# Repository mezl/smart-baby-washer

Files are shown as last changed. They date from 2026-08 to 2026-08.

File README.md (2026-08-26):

<h1 align="center">Smart Baby Washer</h1>

<p align="center">
  <b>App and Home Assistant control for a baby-bottle washer, from an ESP32-C3
  that plugs inline on the panel cable.</b>
</p>

<p align="center">
  
  
  
  
  
</p>

<p align="center">
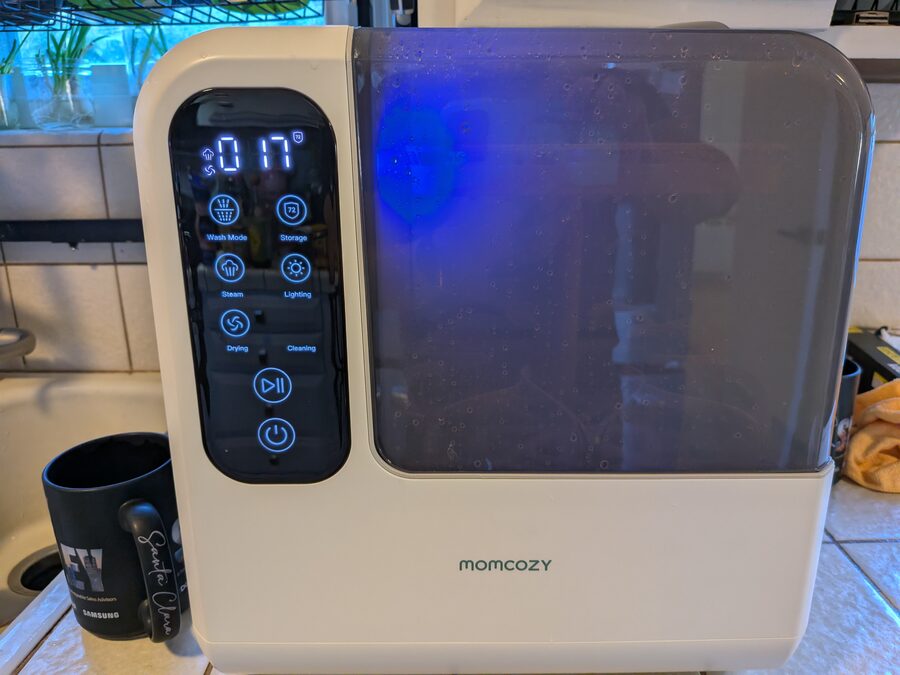
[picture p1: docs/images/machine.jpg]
A Momcozy D8 bottle washer on a kitchen counter, front panel lit, running a cycle.
  
</p>

- Sits on the 4-pin serial link between the front panel and the controller board,
  forwarding every frame and rewriting any byte in flight.
- **Reversible** — `CN2` is a plug-in connector, so the module goes inline on the
  existing cable. Nothing cut, nothing soldered to the OEM board.
- ⚠️ **Verified on two Momcozy D8 units** — an early button-panel one (board
  `BBW04001-UL-P`) and a later touch-panel one. Same firmware, unmodified, on
  both. See [what differs](#what-differs-between-the-two-units)

<p align="center">
  The ESP32-C3 sits on the CN2 UART between the main board and the front panel, and bridges to Home Assistant over WiFi.
</p>

## What it does

- **Web app + HTTP API** — pick a program, start/stop/resume, watch state,
  temperature and stage.
- **Home Assistant** — sensors, buttons, dashboard, notifications. Plain REST; no
  MQTT, no custom component.
- **Cycle runner** — six stock programs plus six of your own; durations and
  temperature targets persist; fills end on flow count, not a timer.
- **Interlocks the machine lacks** — no heater without a verified fill; pause on
  lid-open or no water; abort on over temperature, fill stall, fault bit or dead link.
- **Diagnostics** — drive each load on its own, inject `E0` `E3` `E4` `E5` `E7`
  (`E1`/`E6` have no bit), or run a whole cycle with nothing energised.
- **Live link decode** both directions, raw and rewritten, with temperature and
  flow graphs.
- Local only, no cloud. Logging is host-side; the ESP32 stores nothing.

<p align="center">
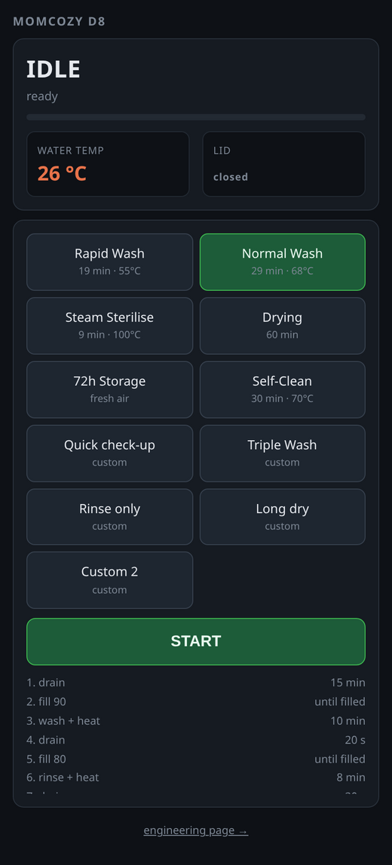
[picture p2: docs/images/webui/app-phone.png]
The app on a phone: state and water temperature, a grid of wash programs with one selected, a START button and the stage list.
  
</p>

<p align="center">
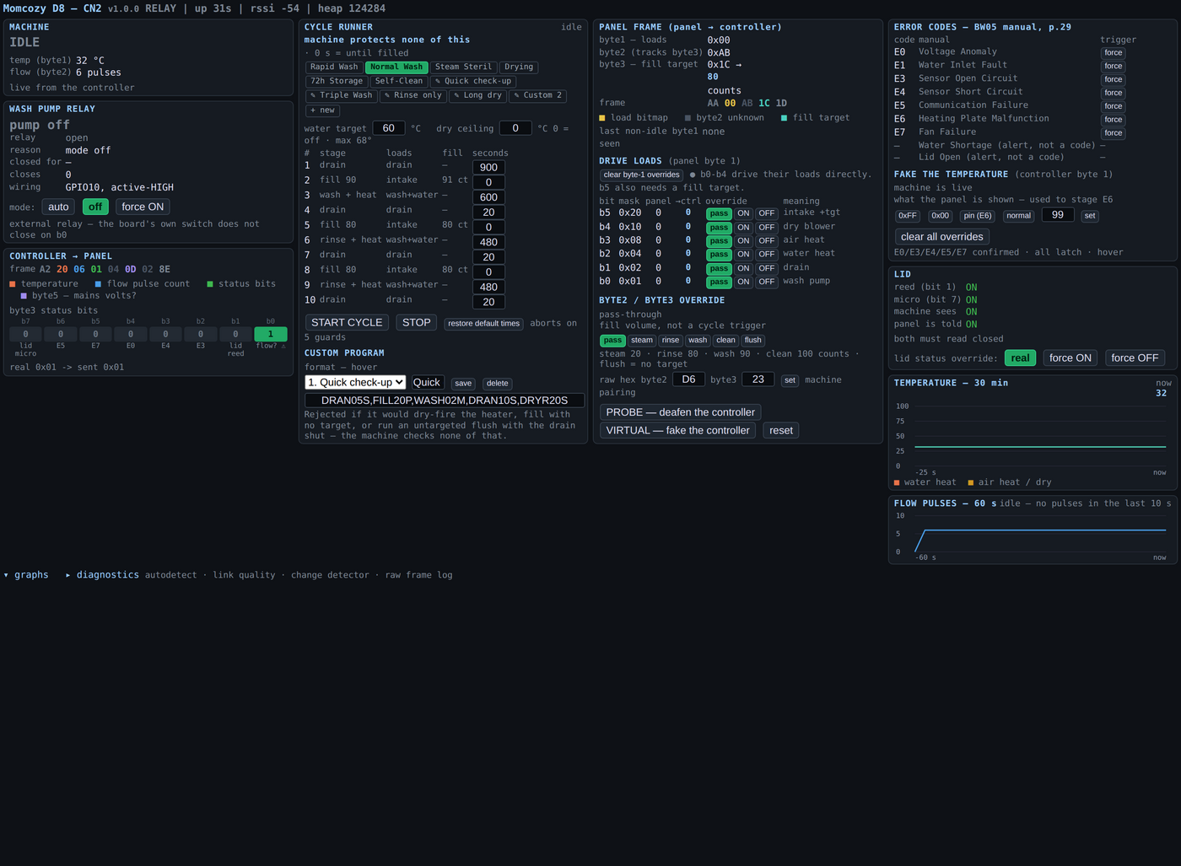
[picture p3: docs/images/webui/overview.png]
The engineering web page: machine state, wash pump relay, decoded frames, cycle runner, error codes, lid status, and temperature and flow graphs.
  
</p>

> ⚠️ It can drive 120 V heaters and a water pump directly, and the machine's own
> controller will not stop you. Read [`docs/safety.md`](docs/safety.md) first.

<p align="center">
  Timelines of a wash cycle and a self-clean cycle: temperature curve above six load lanes, every fill marked with its commanded target and the flow count delivered.
</p>

## What you build

- XIAO ESP32-C3 + a 4-channel BSS138 level shifter. Perfboard is enough; the
  carrier board in [`hardware/pcb/`](hardware/pcb/) is tidier, not better.
- Ground and +5 V pass straight through, so the panel never loses supply.
- ⚠️ Wire to the shifter's **printed pad names** — with HV facing the machine the
  pads read 4·3·2·1 down the board. The photo inset in the diagram shows it.
- 💡 Fit the external antenna. Inside a metal and wet plastic appliance the
  on-board one struggles, and losing WiFi means losing OTA.

<p align="center">
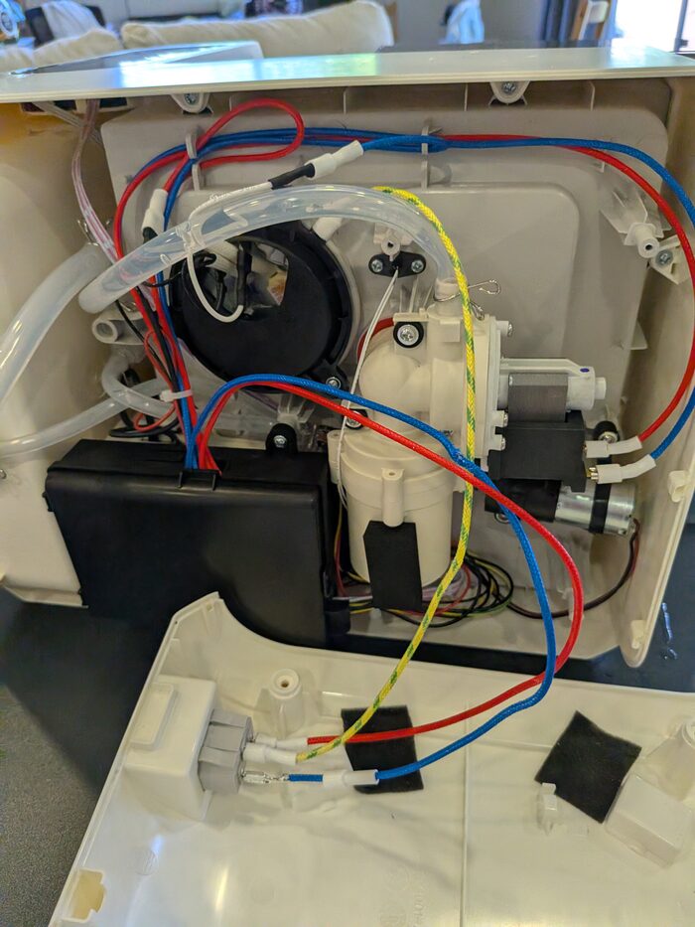
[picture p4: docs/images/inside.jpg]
The washer opened up: pump, tubing and wiring loom inside the base.
  
  &nbsp;
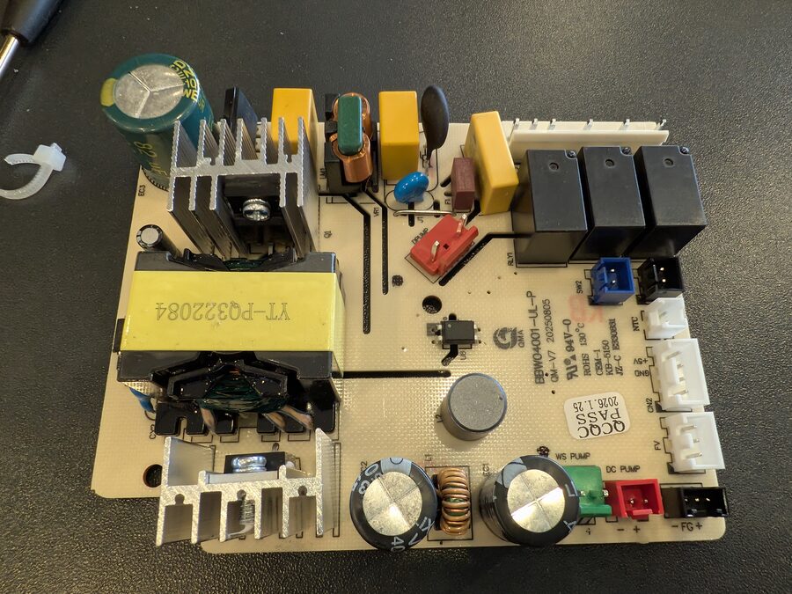
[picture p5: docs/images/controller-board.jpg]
The controller board out of the machine, showing the mains relays, the low-voltage connectors and the CN2 panel header.
  
</p>

<p align="center">
  As-built wiring: the controller and front panel connected through all four channels of a BSS138 level converter to a XIAO ESP32-C3, with power and ground passing straight through.
</p>

<p align="center">
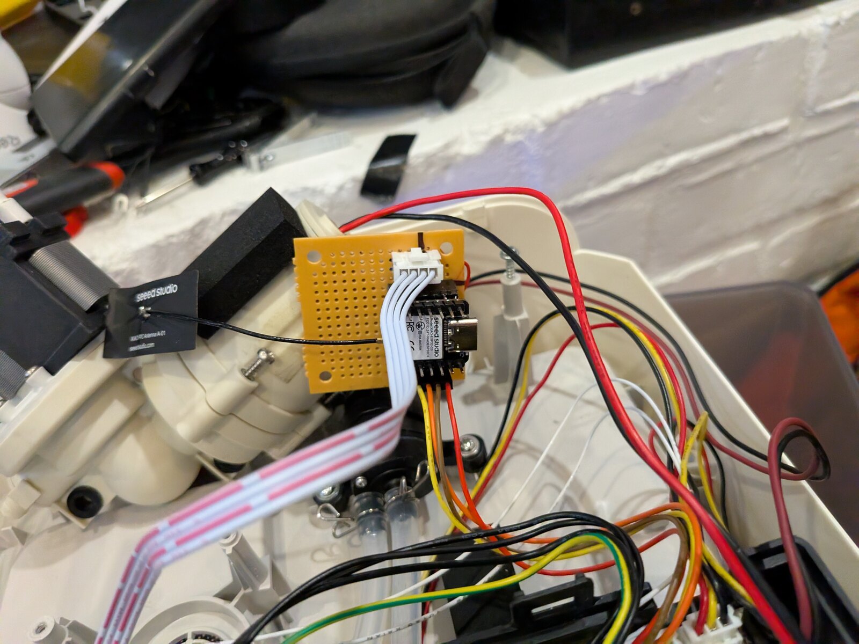
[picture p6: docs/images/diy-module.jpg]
The finished module inside the machine: a XIAO ESP32-C3 on a scrap of perfboard with a 4-pin JST lead to the panel link and an external antenna, tucked beside the pump and wiring loom.
  
</p>

## Quick start

```bash
cp firmware/include/secrets.h.example firmware/include/secrets.h   # WiFi + OTA password
cd firmware
pio run -e c3 -t upload
```

- Open `http://baby-washer.local/`.
- **Start in LISTEN mode** — it cannot drive a line, so nothing can hurt the
  machine while you confirm the wiring.

## Docs

1. ⚠️ [**safety.md**](docs/safety.md) — what the machine does *not* protect you from
2. [**build.md**](docs/build.md) — parts, tapping the link, level shifting, wiring
3. [**flash.md**](docs/flash.md) — firmware, OTA, not bricking it out of reach
4. [**use.md**](docs/use.md) — the app, the engineering page, Home Assistant

Reference: [board.md](docs/board.md) · [protocol.md](docs/protocol.md) ·
[water-plumbing diagram](docs/diagrams/water-plumbing.svg) ·
[cycles.md](docs/cycles.md) · [api.md](docs/api.md) ·
[troubleshooting.md](docs/troubleshooting.md) · [hardware/pcb/](hardware/pcb/)

## Does it fit my machine?

Verified on **two** Momcozy D8 units — an early one (board `BBW04001-UL-P`,
button panel) and a later one (touch panel). Same 9600 8N1 link, same frame
layout, same load bitmap, and the same firmware ran both unmodified.

| | |
|---|---|
| Momcozy D8, either revision | works; the differences below are cosmetic to the protocol |
| Another Momcozy, different board | the link will likely decode, but treat every load bit as unknown until you watch it act |
| Any washer with a separate panel | the approach applies; everything past that is your own work |

- Minimum requirement: a separate front panel talking to a controller over a 4-pin
  connector carrying ground, +5 V and two signal lines.
- [`docs/protocol.md`](docs/protocol.md) has the frame format;
  `POST /api/detect` finds the pin map without ever driving a line.
- A capture from a non-D8 machine is useful — open an issue with `/api/frames`
  output and the board part number.

### What differs between the two units

Measured across 4165 frames from the early unit and 1699 from the later one.

| | early (button panel) | later (touch panel) |
|---|---|---|
| controller byte 6 | `0x02` | **`0x03`** — the only byte that differs by revision |
| controller byte 4 | `0x04` | `0x04` |
| status bit 6 | seen only when starved of panel frames | also asserted **spontaneously**, held for hours, with a byte-perfect link |
| lid bits (1 and 7) | reported normally (`0x02`, `0x80`, `0x82`) | **never seen set** in any capture |
| wash pump on `b0` | low-side switch **does not close** — needs the external relay | **works** — no relay needed |
| fill targets | `0x07 / 0x1C / 0x20 / 0x23 / 0xFF` | same five values |
| heater duty | alternates `wash+heat` ↔ `wash-pump-only` | same |

Two of those matter in practice:

⚠️ **`b0` works on the later unit.** The external wash-pump relay in
[build.md](docs/build.md) is a workaround for the early board's dead low-side
switch. Check yours before wiring a relay it does not need — command `b0` during
a wash and listen.

⚠️ **Status bit 6 is the controller's panel-frame-starvation latch.** On the
later unit it latches until mains removal; the panel renders it as `E5`. Any
gap in forwarding — a slow boot, a wedged relay, an interrupted OTA — can
trip it, which is why the firmware bridges the pads in the first milliseconds
of `setup()` and why you should never flash mid-cycle. The full investigation,
including the wrong turns, is in [`docs/postmortem.md`](docs/postmortem.md).

**Do not assume the error-code table transfers.** Ours comes from the early
unit's manual (`BW05`, p.29). A later panel may number its codes differently,
and reading `E5` as "communication failure" on a machine whose link is provably
clean will send you a long way in the wrong direction.

## Licence

MIT — see [`LICENSE`](LICENSE). No affiliation with Momcozy. Names and part
numbers appear for identification only.

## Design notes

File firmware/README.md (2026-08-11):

# D8 CN2 panel-link sniffer / relay

ESP32-C3 firmware: a transparent man-in-the-middle on the CN2 link that forwards
every byte and can rewrite any of them in flight.

```bash
cp include/secrets.h.example include/secrets.h    # then edit it
pio run -e c3 -t upload                           # USB
OTA_PASSWORD=... pio run -e c3_ota -t upload      # WiFi, by mDNS
pio test -e native                                # 45 host-side cases
./tools/coverage.sh                               # + line/branch coverage
```

PlatformIO, Arduino framework, no external library dependencies. The pure frame
logic — framing, checksums, byte rewriting, the streaming checksum, thinning and
the autodetect decisions — lives in [`lib/cn2core/cn2core.h`](lib/cn2core/cn2core.h)
with no Arduino dependency, so it runs on a host at 100 % line and branch
coverage. `src/cn2.cpp` calls into that same header, which is what stops the tests
drifting into a parallel copy of the logic.

Then open `http://baby-washer.local/` — the user app — or `/dev` for the
engineering page.

⚠️ **Start in LISTEN mode.** It cannot drive a CN2 line at all. See
[`docs/wiring.md`](../docs/build.md#3-tap-it--listen-first).

## Everything else

| | |
|---|---|
| wiring, pin choice, level shifting | [`docs/wiring.md`](../docs/build.md) |
| the protocol | [`docs/protocol.md`](../docs/protocol.md) |
| HTTP API | [`docs/api.md`](../docs/api.md) |
| web UI | [`docs/webui.md`](../docs/use.md) |
| OTA design and its guards | [`docs/ota.md`](../docs/flash.md) |
| diagnosis | [`docs/troubleshooting.md`](../docs/troubleshooting.md) |
| ⚠️ what the machine does not protect you from | [`docs/safety.md`](../docs/safety.md) |

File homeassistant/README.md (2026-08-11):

# Home Assistant

Two files. No MQTT broker, no custom component, no cloud — HA polls the ESP32's
HTTP API directly.

```
packages/momcozy_d8.yaml    entities, commands, automations
lovelace-dashboard.yaml     the dashboard
```

## Install

1. Copy `packages/momcozy_d8.yaml` into `config/packages/`
2. In `configuration.yaml`:

   ```yaml
   homeassistant:
     packages: !include_dir_named packages
   ```

3. Set the ESP32's address — it appears **four times** in the package, in the
   `rest:` block and the three `rest_command:` entries
4. Restart HA
5. Settings → Dashboards → new dashboard → ⋮ → **Raw configuration editor** →
   paste `lovelace-dashboard.yaml`

## What you get

| Entity | |
|---|---|
| `sensor.d8_state` | Idle / Running / **Paused** / Complete / Stopped |
| `sensor.d8_water_temperature` | °C, uncalibrated and reads low |
| `sensor.d8_flow_count` | fill counter — cumulative for the **current fill**, zeroed by the controller when it completes |
| `sensor.d8_program` | the program the machine is set to |
| `sensor.d8_stage` | `3/10 — wash + heat` |
| `sensor.d8_error` | `E0`/`E3`/`E4`/`E5`/`E7`, or `none` |
| `binary_sensor.d8_running` | |
| `binary_sensor.d8_paused` | lid open, or the tank needs refilling |
| `binary_sensor.d8_lid` | on = **open** |
| `binary_sensor.d8_fault` | |
| `input_select.d8_program` | two-way — follows the machine if changed elsewhere |
| `script.d8_start_cycle` / `d8_stop_cycle` / `d8_resume_cycle` | |

Plus notifications when a cycle finishes or stops, and when a fault appears.

## ⚠️ What this actually controls

A cycle started from HA does **not** press the machine's buttons. Nothing the
panel does before it commands a load reaches the CN2 link, so there is no button
to press remotely. It runs the **ESP32's own cycle runner**, which drives every
load directly.

That matters because the machine protects almost none of it. Measured, not
assumed: the controller gates nothing except the intake motor, the heaters fire
with no water and the lid open, and **neither end has a fill timeout**. The
runner's interlocks are the only ones in the loop — see
[`../docs/safety.md`](../docs/safety.md) and
[`../docs/cycle.md`](../docs/cycles.md).

So:

- **Starting a cycle is a `script`, not a `switch`**, and every command is a
  `button`-style action. A stuck automation cannot leave a heater latched on.
- `script.d8_start_cycle` **refuses if the lid is open.** The machine itself will
  not.
- There is deliberately no "start at 3 am" example. Do not run this unattended.

## Notes

**Fault codes latch.** Clearing the condition is not enough — the machine needs a
power cycle before it will run again. The dashboard says so when a fault is
showing.

**Polling is 5 s.** The ESP32's own page polls at 1 Hz; 5 s is plenty for a
machine whose stages last minutes, and it keeps HA's recorder small. Lower
`scan_interval` if you want a tighter flow-count trace, but the device-side ring
at `/api/flowlog` is the right tool for per-pulse detail.

**Program indices** in `input_select` must match the firmware's order. If you
reorder the programs in `cn2.cpp`, reorder the list here too.

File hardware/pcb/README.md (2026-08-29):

# CN2 interceptor carrier board

A 18.6 × 27 mm, 2-layer carrier that sits in the CN2 cable between the D8
controller and its front panel. CN2 pins 3 and 4 (GND, +5 V) pass straight
through; pins 1 and 2 are routed through a level shifter to a XIAO ESP32-C3,
which then sees and can rewrite every byte in both directions.

<p align="center">
  Board: red = top copper, blue = bottom copper. J2 (panel) on the bottom edge, J1 (controller) on the top edge, level shifter nested between the XIAO's pin rows.
</p>

**J2 (panel) on the bottom edge, J1 (controller) on the top**, with the XIAO
between them and U2 nested *inside* the XIAO's 15.24 mm row gap — its own rows
are 10.16 mm apart, so it drops straight into the middle.

Standing the connectors on opposite edges rather than beside the XIAO is what
makes the board narrow: nothing sits left or right of the module except one
routing lane, so the width is the XIAO's row pitch plus that lane and two
edges. It also suits the cable run, since the two CN2 stubs leave the board in
opposite directions, the way they arrive.

### Which connector goes where is not arbitrary

Routing forces `LV1..LV4` onto `D1..D4` in order — they share a 0.94 mm channel
and any other order makes their spans overlap four deep. `D1..D4` are GPIO 3, 4,
5 and 6, and the firmware's as-built map is `rxb=5 txb=6 txp=3 rxp=4`: the
**controller** pair on GPIO5/6 and the **panel** pair on GPIO3/4. GPIO5/6 are
channels 3 and 4, which are the shifter's upper pins — so the controller has to
enter from the top edge.

Swap the connectors and the board still works, but only after swapping the four
`PIN_*` defines. `gen_pcb.py` reads `firmware/include/config.h` on every run and
fails if the two disagree, because a pin map that disagrees with the copper does
not announce itself: frames simply stop decoding.

## ⚠️ Mount U2 on the underside

Packing the shifter inside the XIAO's rows puts the two modules on top of each
other in plan view:

```
XIAO module   17.5 × 21.0 mm   x  0.22 .. 17.72    y  3.00 .. 24.00
shifter       15.7 × 13.2 mm   x  1.12 .. 16.82    y  6.90 .. 20.10
```

The shifter's outline sits entirely inside the XIAO's. On 2.54 mm sockets the
XIAO stands about 8.5 mm off the board and the shifter plus its own headers is
about 12 mm, so **they collide if both are fitted on top.**

**Solder U2 to the reverse side.** The pads are plated through-holes, so it makes
no difference electrically, and the two modules then sit back to back with the
PCB between them. Nothing in the Gerbers changes — it is purely an assembly
choice, but getting it wrong wastes a board.

If you would rather have both parts on top, put the shifter beside the XIAO
instead of between its rows; that costs roughly 14 mm of board length.

## Reading the silkscreen

| Mark | Meaning |
|---|---|
| `PNL` / `CTL` | which cable goes on which edge — panel bottom, controller top |
| `USB` + arrow | the end the XIAO's USB-C port faces |
| `[` `]` bracket | the side the JST latch faces on J1 and J2 |
| square pad | pin 1, on every connector and both modules |

**The USB arrow matters.** `D0` and `5V` are the two pins at the USB end of the
XIAO, and both sit at the low-y end here, so the port faces the **panel**
connector. Fit the module the other way round and every signal lands on the
wrong pin — there is no keying to stop you, and the board looks right.

**The bracket is the JST latch side.** An XH shroud is not symmetric: the ramp
the cable's clip engages is on one long side. Both are marked facing the nearest
board edge, so the clips are reachable from outside once the board is mounted.
Fit one backwards and the clip faces the board and cannot be released.

### ⚠️ USB access is tight — socket the XIAO, and plug USB in first

The USB port faces J2, about 1.4 mm from the connector. On 2.54 mm sockets the
module stands ~8.5 mm off the board, so the port clears the JST *housing* — but
a **mated** panel cable stands about as tall as the USB plug and sits directly
in front of it.

In practice: **plug the USB cable in before the panel cable**, or leave the
panel cable's service loop long enough to swing aside. This is not theoretical
— a whole debugging session on this project ran over USB serial with the radio
disabled, so losing USB access once assembled is a real cost.

If you would rather not live with it, both connectors can go on the **top**
edge, leaving the USB end of the board clear. Two 4-pin connectors need about
19.5 mm side by side, so the board becomes roughly 21 × 24 mm — near enough the
same area, with the USB fully accessible.

## Bill of materials — four parts

| Ref | Part | Notes |
|---|---|---|
| J1 | JST-XH 4-pin, 2.54 mm, vertical | **top** edge — cable to the **controller** CN2 |
| J2 | JST-XH 4-pin, 2.54 mm, vertical | **bottom** edge — cable to the **panel** CN2 |
| U1 | Seeed XIAO ESP32-C3 | 2×7, 2.54 mm pitch, 15.24 mm between rows |
| U2 | 4-channel BSS138 level shifter | 2×6, 2.54 mm pitch |

Plus two 1×7 and two 1×6 header strips if you want the modules socketed rather
than soldered down. Socketing the XIAO is worth it — it keeps `D5`, `D10` and
`D7` reachable for the flow and switch simulation, which is why the board carries
no separate header for them.

## The flow-meter relay is not on this revision

The previous board carried J3/J4, a relay for the flow-meter (FV) cable, so the
ESP32 could pass the real pulses through, rewrite their rate, or synthesise flow
on a dry bench. **It has been removed**, and that removal is most of the size
reduction: six more pins would not share an edge with the CN2 connectors, so
they forced the connectors back onto the left and right sides and the width from
18.6 mm to 31.5 mm — the flow relay cost more board than everything else on it.

If you put it back, the two findings that cost the most to learn are still worth
having:

- **The ESP32-C3 is not 5 V tolerant and there is no channel left to shift the
  flow signal** — all four converter channels are spoken for by CN2.
  `docs/hardware.md` records the meter as having a 10 kΩ internal pull-up and
  warns that running it at 5 V puts 5 V on a non-5V-tolerant GPIO. Measure FV
  Vcc first; if it is 5 V, `GPIO10` needs a divider, or feed the meter from the
  board's 3V3 so the whole signal drops to 3.3 V.
- **Cutting the line removes the meter's pull-up from the controller's input**,
  because that pull-up lives inside the meter and ends up on the far side of the
  break. The simulated output then has to drive the line actively, or the
  controller-side pin needs its own pull-up.

Only `GPIO7` (D5), `GPIO10` (D10) and `GPIO20` (D7) are free and safe on this
part — `GPIO2`, `GPIO8` and `GPIO9` are strapping pins and `GPIO21` emits ROM
boot chatter at every reset. All three stay reachable on the XIAO's own header
if you socket the module, which is the main reason to socket it.

## Connections

| ch | CN2 | | Converter | XIAO | UART |
|---|---|---|---|---|---|
| 1 | J2 PANEL pin 1 — RX, **input** | ← | `HV1` · `LV1` | `D1 / GPIO3` | `Serial1` **TX** |
| 2 | J2 PANEL pin 2 — TX, output | → | `HV2` · `LV2` | `D2 / GPIO4` | `Serial1` **RX** |
| 3 | J1 CONTROLLER pin 1 — TX, output | → | `HV3` · `LV3` | `D3 / GPIO5` | `Serial0` **RX** |
| 4 | J1 CONTROLLER pin 2 — RX, **input** | ← | `HV4` · `LV4` | `D4 / GPIO6` | `Serial0` **TX** |

That is `PIN_RX_BOARD 5`, `PIN_TX_BOARD 6`, `PIN_TX_PANEL 3`, `PIN_RX_PANEL 4` —
the as-built map already in `firmware/include/config.h`, so **a board built from
this needs no firmware change.** `gen_pcb.py` asserts it on every run.

Note this differs from the channel order in
[`docs/wiring.md`](../../docs/wiring.md#as-built--the-authoritative-table), which
describes the hand-wired module: there the controller landed on channels 1 and 2.
The electrical result is identical; only which pair uses which converter channel
moved, so that the connectors could sit on opposite edges.

**The rule that decides every connection is unchanged:** an *output* stub must
land on an ESP32 **RX** pin, an *input* stub must be **driven** by an ESP32 **TX**
pin. Wiring a TX pin to another output is the one way to damage a board.

Power: controller pin 4 = panel pin 4 = converter `HV` = XIAO `5V`, one net.
XIAO `3V3` → converter `LV`. All grounds common.

## ⚠️ Measure the level shifter before ordering

**Row spacing on 4-channel BSS138 modules is not standardised.** SparkFun's
BOB-12009 and most clones use 0.4″ (10.16 mm), but 0.5″ (12.7 mm) modules exist
and look identical in photos. Put calipers across yours, centre of one row to
centre of the other, then set `LS_ROW` at the top of `gen_pcb.py` and regenerate.

This is the single most likely way to get an unusable board back from the fab.

## How small it can go

18.6 × 27 mm is 502 mm², **39 % smaller than the 819 mm² it replaced** and
**41 % narrower** — which is the dimension that decides whether it fits a slot.

The width is now fully accounted for, and there is nothing left in it:

```
  0.5  edge
 16.8  XIAO pad block  (15.24 row pitch + 1.6 pad)
  0.4  clearance
  0.4  the one outer lane, shared by +5V (top) and GND (bottom)
  0.5  edge
 ─────
 18.6
```

The four CN2 signals never need a side lane at all: each connector pin sits
directly under the middle corridor, so it climbs straight out of its own pad
into its shifter pin, turning once. Only +5V and GND have to reach both the
XIAO's right-hand column and both connectors, and they share the single outer
lane one per layer. Remove that lane and the board is 17.8 mm, but those two
nets have nowhere to go.

**The height is set by the XIAO's body, not by its copper.** The pads span
15.24 mm; the module is 21.0 mm long, so it overhangs 2.88 mm at each end,
straight over the connectors. At 24 mm the modules physically sit on both JST
housings — the Gerbers look perfect and the boards arrive unbuildable.
`gen_pcb.py` now checks the module outlines against every connector pad on each
run for exactly this reason.

Going further would need **right-angle connectors** (the overhang stops
mattering and the board returns to ~24 mm), **discrete BSS138s instead of the
module**, which removes 12 through-holes and the nesting problem entirely, or
**4 layers**. Note that none of this saves money: JLCPCB charges the same for
anything up to 100 × 100 mm, so size only buys fit.

## Panelised for a JLCPCB minimum order

JLCPCB's minimum order is **5 pieces**, and its base tier covers any single
design up to **100 × 100 mm** — so a panel of copies costs what one small board
costs. `gen_panel.py` tiles the board into the largest grid that still fits:

```
  5 × 3 = 15 boards      panel 93.0 × 81.0 mm      5 panels = 75 boards
```

```bash
python3 gen_panel.py        # 5 x 3, the largest that fits
python3 gen_panel.py 3 2    # or any smaller grid
```

Output lands in `gerbers-panel/`, with `preview-panel.svg` to eyeball first.
The generator re-runs the board's DRC, connectivity, mechanical and pin-map
checks and refuses to panelise if any fail — a panel of a broken board is 15
broken boards.

### V-scoring, not mouse bites

The boards **abut with no gap**, which is what lets 15 fit. V-scoring needs a
straight line running the full width or height of the panel, and a grid of
identical rectangles is exactly that. Tab-routing would need a ~2 mm slot
between every pair and would cost a column.

Nothing had to change to make the copper safe for it: the board already keeps
every pad and track **0.5 mm** from its edge, and V-scoring wants 0.4 mm.

**The score lines are on their own layer** (`-V_Cut.gbr`), deliberately not on
`Edge_Cuts`. Anything on the outline layer is read as a route, and a router
following those lines would cut the panel into 15 loose boards at the fab
instead of scoring it. `Edge_Cuts` carries the panel border and nothing else.

### Ordering

Upload `gerbers-panel/` as a zip, then on the order page:

| Field | Value |
|---|---|
| Different Design | **1** |
| Delivery Format | **Panel by Customer** |
| Column × Row | **5 × 3** |
| Board size | 93 × 81 mm (JLC fills this from the Gerbers) |

Add a note asking for **V-scoring on the lines in `cn2-interceptor-panel-V_Cut.gbr`**.
Check their rendered preview before paying — it shows the score lines, and that
is the one place a misread would be visible before it is fabricated.

Panelised orders sometimes carry a small surcharge and the rules do change, so
confirm the price at upload rather than trusting this table. If it has moved,
`python3 gen_panel.py 2 2` gives four boards on a 37 × 54 mm panel, and a plain
single board is always `gerbers-kicad/`.

## Files

| | |
|---|---|
| `gen_pcb.py` | the board as explicit geometry — placement, nets, routing, its own DRC, preview |
| `gen_panel.py` | tiles the board into a JLCPCB-sized panel with V-score lines |
| `gen_kicad.py` | builds a native `.kicad_pcb` via the pcbnew API **and runs KiCad's own DRC** |
| `gen_eagle.py` | emits `.sch` and `.brd` from the same model |
| `gen_kicad_sch.py` | emits a native `.kicad_sch` from the same model |
| `cn2-interceptor.kicad_pcb` | native KiCad 7 board — open it, DRC it, edit it |
| `cn2-interceptor.kicad_sch` | native KiCad 7 schematic — nets joined by labels |
| `cn2-interceptor.sch` / `.brd` | Eagle 9 XML, for Eagle / Fusion 360 |
| `gerbers-kicad/` | **exported by KiCad itself** — this is the set to send to a fab |
| `gerbers/` | my own writer's output, kept as a cross-check |
| `gerbers-panel/` | **the 5 × 3 panel** — upload this zip for a 15-up order |
| `drc-report.txt` | KiCad's DRC output from the last run |

Regenerate everything:

```bash
python3 gen_pcb.py      # geometry DRC + connectivity + my gerbers + preview.svg
python3 gen_kicad.py    # .kicad_pcb + KiCad's own DRC report
python3 gen_kicad_sch.py  # .kicad_sch
python3 gen_eagle.py    # .sch + .brd   (refuses to run if the DRC fails)

kicad-cli pcb export gerbers --output gerbers-kicad \
  --layers F.Cu,B.Cu,F.Mask,B.Mask,F.SilkS,Edge.Cuts \
  --no-x2 --subtract-soldermask cn2-interceptor.kicad_pcb
```

There is one source of truth. The schematic, the board and the Gerbers are three
renderings of the same Python model, so they cannot drift apart.

## What has been checked, and what has not

**Checked by KiCad itself** (`gen_kicad.py`, via `pcbnew.WriteDRCReport`):

```
violations       0   (excluding 4 lib_footprint_issues, see below)
unconnected pads 0
footprint errors 0
```

The four remaining reports are all `lib_footprint_issues: the current
configuration does not include the library 'cn2interceptor'` — the footprints are
generated into the board file rather than pulled from an installed library, so
KiCad cannot find a library to check them against. That is a bookkeeping
complaint, not a geometry or connectivity one.

**Checked by `gen_pcb.py`** on every run, independently of KiCad:

- 2186 pairwise clearance checks at 0.20 mm — copper-to-copper on each layer,
  and every track against every through-hole pad on both layers
- annular ring ≥ 0.30 mm, drill ≥ 0.30 mm, 0.5 mm edge keepout
- connectivity: every pad is on a net, every net has ≥ 2 pads, and every net
  forms a single connected island rather than two stranded halves
- both Eagle files parse as well-formed XML
- the board's pin map is compared against `firmware/include/config.h` and the
  run fails on a mismatch
- module bodies (not just their pads) are checked against every connector pad
- silkscreen is checked to stay on the board and off every pad

**Not checked.** Be clear-eyed about this list:

- **Nothing has been fabricated.** No board has been made or assembled.
- **The Eagle `.sch`/`.brd` have not been opened in Eagle or Fusion.** They parse
  as well-formed XML and are generated from the same verified model, but no Eagle
  install has confirmed they import cleanly. The KiCad board has been through
  KiCad's own DRC and Gerber export.
- **No ERC has been run.** KiCad 7's CLI has no `sch erc` command (that arrived
  in KiCad 8). The `.kicad_sch` parses and plots cleanly through `kicad-cli sch
  export`, which is not the same as passing ERC — open it in Eeschema and run
  ERC if you want that confirmed.
- **Footprint dimensions come from datasheets, not from measuring your parts.**
  The XIAO's 15.24 mm row spacing is well documented; the level shifter's is not
  — see the warning above.
- **No thermal or current analysis.** It carries logic signals and the panel's
  own 5 V supply, which the OEM cable already carried, so this is unlikely to
  matter. It has not been calculated.

**Before ordering:** open the Gerbers in a viewer (JLCPCB and PCBWay both show
you the rendered board at upload), check the level shifter footprint against your
actual module, and confirm the JST-XH pin order matches your cable.

## Safety

The board carries the panel's 5 V supply and its data lines. It does not touch
mains. But what you can then *do* with it does —
see [`docs/safety.md`](../../docs/safety.md): byte 1 of the panel frame is a
direct load bitmap, and three of its bits fire heaters with no cycle running and
no water in the machine.

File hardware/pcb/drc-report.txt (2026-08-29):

** Drc report for  **
** Created on 2026-08-29 16:27:00 **

** Found 4 DRC violations **
[lib_footprint_issues]: The current configuration does not include the library 'cn2interceptor'.
    Local override; Severity: warning
    @(3.8900 mm, 7.1500 mm): Footprint U2
[lib_footprint_issues]: The current configuration does not include the library 'cn2interceptor'.
    Local override; Severity: warning
    @(1.3500 mm, 5.8800 mm): Footprint U1
[lib_footprint_issues]: The current configuration does not include the library 'cn2interceptor'.
    Local override; Severity: warning
    @(5.1600 mm, 25.4000 mm): Footprint J1
[lib_footprint_issues]: The current configuration does not include the library 'cn2interceptor'.
    Local override; Severity: warning
    @(5.1600 mm, 1.6000 mm): Footprint J2

** Found 0 unconnected pads **

** Found 0 Footprint errors **

** End of Report **

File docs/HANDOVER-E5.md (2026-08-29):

# HANDOVER: Momcozy D8 "unit 2" E5-at-boot — for the next agent

Written 2026-08-27 by the outgoing agent after a three-day investigation that
fixed everything except this. Read `postmortem.md` and `boot-review.md` after
this file; they carry the full evidence chains. Trust the measurements in
this document; distrust every narrative, including mine.

## 0. The one-line problem

Since Aug 26 ~17:45, the washer's controller latches status **bit 6** (panel
shows **E5**) ~5 s after every power-on **when the ESP32 interceptor module
is inline**, and boots clean when the panel cable is connected directly
(bare). The machine worked perfectly with the same module, same firmware,
same NVS at 15:31 the same day. Nothing that is constant across that
boundary can be the cause; everything software-side has been proven constant
or was wiped.

## 1. System map

- **Machine**: Momcozy D8 bottle washer, later touch-panel revision.
  Controller board talks to front panel over `CN2` (4-pin: GND, +5V, two
  UART lines, 9600 8N1). Frame formats in `docs/protocol.md`.
- **Module**: XIAO ESP32-C3 + 4-ch BSS138 shifter, INLINE on CN2 (cable cut,
  both halves land on the module). Powered FROM CN2 pin 4 → it reboots with
  the machine. **As-wired pin map: rxb=5 txb=6 txp=3 rxp=4** (differs from
  docs/build.md which describes 3/4/5/6 — the owner rebuilt it Aug 25; NVS
  map matches physical, verified: frames decode on 5/4, dead on 3/6).
  IP `192.168.14.13`, mDNS `d8-sniffer.local`. Firmware in this repo,
  `firmware/`; deployed 1.17.7. OTA: `POST /update?key=<OTA_PASSWORD>` —
  password in `firmware/include/secrets.h` (gitignored, on the dev box).
- **Smart plug**: Shelly Plug US **Gen4** `192.168.14.95`, name "D8 Washer",
  `initial_state=on`. HTTP RPC, no auth. Real power metering. `toggle_after`
  gives a true self-restoring power cycle — `tools/shelly.py`
  (status/on/off/cycle) or `POST <esp>/api/kasa?cycle_s=N`.
- **HA**: `homeassistant.local:8123` (ssh alias `ha`, key auth, /config).
  Shelly integration live; `packages/momcozy_d8.yaml` REST-polls the ESP.
  Dashboard tab: `/dashboard-cradlewise/d8`. NO daemons — owner directive:
  ESP32 must be self-contained; HA is display-only.
- **Repos**: `~/software/d8-smart` (private, full history) and
  `~/software/smart-baby-washer` (public mirror). Firmware source of truth
  the owner edits from: `~/software/momcozy_d8/cn2sniffer`.

## 2. Owner directives (standing, do not violate)

- CPU relay is the operating mode; NEVER auto-switch to wire mode. Wire is a
  diagnostic, on explicit request. (Both persist via NVS `wire`.)
- No PC/HA daemons in the run/recovery path.
- Self-heal (`/api/heal`) is opt-in OFF; its strike counter resets only by
  human command. It once power-cycled the machine all night — see §6.
- Repos stay private until the owner flips them; never commit secrets.

## 3. Tooling you have

- ESP API: `/api/status` (everything), `/api/frames?n=` (timestamped ring,
  ~60 s deep), `/api/hist` (dedup frame history; array is oldest→newest,
  `first/last` = frames-ago — MISREAD TWICE, cost hours), `/api/graph`
  (temp/flow/power trends), `/api/panel_ovr`, `/api/mode_ovr`, `/api/wire`
  (GET shows live+stored), `/api/pinmap`, `/api/kasa` (`type=shelly`,
  `test`, `cycle_s`), `/api/nvswipe?confirm=yes`, `/api/heal`, `/api/prof`,
  `/api/wirecheck` (edge counts on all four pads — proves conduction).
- `firmware/minimal/main_min.cpp` (env `c3min`): bridge+WiFi+OTA only, the
  exoneration instrument. NOTE: no WiFi reconnect — if a boot misses
  association it stays dark; power cycle again.
- OTA over the flaky link: fresh-boot trick — Shelly `toggle_after=6`, wait
  for `/api/version`, sleep 10–12 s, then upload full speed. Usually lands
  within 4 rounds. Uploads die if attempted on an "aged" link.
- Host tests: `pio test -e native` (111 green, includes the E5Model suite
  that reproduces every firmware-caused E5 class and forbids regressions).

## 4. Precise symptom (from frame captures — `captures/boot-frames-e5-*.txt`)

- Controller boots **clear** (byte3=0x00), replies to the panel's 200 ms
  polls within 3–12 ms, checksums perfect, then latches byte3=0x40 at
  **t≈5.1 s** between two byte-identical polls.
- Controller frame **byte 5**: healthy era idles `0x09` (0b1001); broken era
  `0x0A/0x0B` (bit1 ON; bit0 flickers). It initializes ~0x00→0x0A at
  t≈0.7 s. It has read steady-`09` for stretches (once 5+ minutes) and the
  latch STILL occurred on the next boot — so byte5-bit1 correlates but the
  gate may sample earlier than any window we catch, or byte5 is not the gate.
- The latch survives cuts of 5 s–10 min. Historical cut data (CSV in
  `captures/`): during Aug-23-era locks, 60 s cuts 0/5, 120 s 3/5, 180 s 2/2
  — but the CURRENT condition relatches at every boot regardless.
- A latched controller ignores external load commands (proven: intake+target
  → zero flow; 60 s wash+heat → 0.0 °C rise) but its frames keep flowing.

## 5. The exoneration ladder — do not re-climb it

Each rung was TESTED, not argued (details in postmortem/boot-review):
1. Firmware logic — 20-line minimal image (silicon bridge from first app
   instruction, no logic in data path): **latches**.
2. Image size / boot speed — 23 % smaller, zero init: latches.
3. Every firmware version, incl. rebuilt same-day-working 1.16.3: latches.
4. NVS — full wipe to virgin + minimal re-provision: latches.
5. Pin map — re-verified empirically both ways (decode dead on 3/4/5/6,
   alive on 5/6/3/4).
6. GPIO10 boot drive (real bug, fixed 1.17.3 — wsr pin untouched when off):
   not the cause.
7. Frame content/timing — byte- and ms-identical to working logs.
8. Masks (`e5filter`), wire vs CPU, boot-bridge timing (t≈300 ms): no effect.
9. ROM-stage pad analysis (JTAG pulls on GPIO4/5/6): cannot pull a line low;
   constant since day one.
10. **Bare machine: clean** (owner-run, repeated).

## 6. Open contradictions — the real leads

- **The overnight 38 W**: Aug 26 23:00→Aug 27 08:50, HA's Shelly power
  history shows a flat ~38 W pump-class load for 7.6 h starting AT a boot,
  during virgin-NVS **wire mode** (ESP TX physically detached) with the
  panel E5-latched. Owner states the controller never self-starts loads on
  boot. Then WHO drove 38 W? Unresolved. Suggest: capture what a LATCHED
  panel actually transmits (nobody ever verified it stays idle in all latch
  entry paths), and what byte1 the controller sees at such a boot.
- **The Wednesday 15:31→17:45 differential**: that afternoon contained heavy
  cycle testing (heat, vibration, dozens of hard power cycles) and a flush
  bug that ran water ~2 min (see postmortem). No code change survives the
  elimination ladder. Something PHYSICAL changed. Candidates, in my order:
  BSS138 channel stressed/failing at analog margins; solder joint; CN2
  connector seating; controller input stage damaged; and (weakly) some
  panel/controller NVM state that bare-boot masks — though bare-clean argues
  against controller NVM.
- **byte5 semantics**: never decoded. Bits 0/1 swap between healthy/broken;
  a new value 0x06 appeared once after the pump-night. Manipulating lid,
  tank, buttons moved nothing. Worth mapping properly (drive each machine
  input while streaming `fb`).

## 7. Ranked next experiments

1. **USB split-power test** (decisive, cheap; owner has the module
   accessible): USB-C charger into the XIAO → ESP never reboots with the
   machine → bridge alive from the controller's first microsecond → Shelly-
   cycle the machine. Clean boot ⇒ ROM dark-window timing was the cause AND
   the permanent fix (leave USB in). Latch ⇒ analog presence confirmed.
   Note XIAO diode-ORs USB and 5 V rail; dual feed is safe.
2. **Multimeter on the shifter during a latch** (HV1..4 idle ≈5 V via 10 k
   pull-ups; a dead channel reads floating/low; wiggle-test joints).
3. **Latched-panel transmission capture**: `/api/frames` while the panel
   displays E5 through a fresh latch — verify it truly idles 0x00 in every
   entry path (bears on the 38 W mystery).
4. **Scope/logic-analyzer on CN2 at the controller connector** during a
   module boot vs a bare boot — the only view that sees what the
   controller's input pin actually receives during t=0–5 s.
5. If all else stalls: swap the BSS138 board (~$1) on spec; it is the
   component most exposed to that afternoon's stress and least observable.

## 8. Lessons paid for in hours — read before acting

- `HardwareSerial::setPins(samePins)` is a silent no-op; the GPIO-matrix
  bridge steals pads invisibly to periman. Reconnect TX signals explicitly
  (see wireSet(false)). This one cost 12 hours of ghost-hunting.
- Test UI through a BROWSER, not curl: the board serves ONE http client;
  parallel fetches race and the loser is dropped (chain posts).
- The shared `Preferences s_prefs` handle breaks after any begin()/end()
  pair elsewhere; use local handles for every persist (several fixed).
- A 0xFF flush is controller-LATCHED: stopping it = intake off, drain held
  ~20 s, then release. Plain release leaves water running.
- FramePos alias: idle-stream byte loss self-sustains and XOR-validates;
  detection needs the byte-1 invariant + wire-gap re-lock (in cn2core, host
  tested).
- `pkill -f <pattern>` matching your own command line kills your own shell.
- Owner's instincts have repeatedly out-diagnosed instrument readings.
  When they say "not X", retire X quickly and retest assumptions instead.

## 9. Artifact index

- `docs/postmortem.md` — full multi-day evidence narrative + retractions
- `docs/boot-review.md` — instruction-level boot audit
- `captures/boot-frames-e5-20260826.txt` — the latch, frame by frame
- `captures/unit2-firstcycle-*` — healthy-era reference traffic
- `captures/unlock-attempts.csv`, `ha-*-final.*` — cut/latch field data
- `firmware/test/test_cn2core/` — 111 host tests incl. the E5Model suite
- HA history: `sensor.d8_washer_d8_washer_power` — the overnight 38 W curve

Good luck. The machine's owner wants a washer, not a mystery — if experiment
1 fixes it, stop there and let the analog question rest.

---

## Update 2026-08-28: module went fully dark

The ESP died in place overnight (last alive 2026-08-27 after the 1.17.8
flash, link healthy). Evidence: never associates with WiFi (ARP
incomplete), absent from a full /24 sweep, machine standby draw normal
(1.8 W). Not recoverable remotely: 3 power cycles + 30 s cut + 5-min
cold cut all failed. Chip is not booting.

Significance: strongly supports the hardware-degradation branch. A
failing power path (CN2 pin-4 rail / regulator) explains BOTH the
E5-at-boot onset on 08-26 (rail sag disturbing the link during boot)
AND the final no-boot state -- one fault, progressing.

Decisive test unchanged (= ranked experiment #1, now also the recovery
step): USB-C into the XIAO.
- Boots on USB -> rail/feed dead -> E5 root cause likely found; run the
  module on USB power permanently.
- Dead on USB -> board failed -> replace XIAO, `pio run -t upload`,
  pin map 5/6/3/4 is the compiled default since 1.17.8.

Note: with the module inline and unpowered the panel<->controller link
is SEVERED (bridge exists only while the ESP runs). Machine unusable
until physical access; panel-direct-to-CN2 restores standalone use.

## Update 2026-08-28 (later): machine WORKS with the "dead" module inline -- diagnosis nearly closed

Kai reports the machine working again, module untouched, ESP still absent
from the network. This overturns the "chip not booting" call: the link
physically routes through the module, so a working machine PROVES the
bridge is forwarding, i.e. the CPU boots and runs instantBridge (first
instruction, register-state only, ~uA). Only the RADIO is dead.

Coherent single-fault story, now spanning every observation:
degrading 5V feed (CN2 pin-4 rail / regulator). Quiescent CPU + GPIO
bridge survive; WiFi startup bursts (~300 mA) collapse the rail.
- Pre-08-26: rail healthy -> everything worked.
- 08-26 onward: rail sags during WiFi startup -> link disturbed at
  t~5.1 s after boot (exactly the radio-burst window) -> controller
  latches E5 every boot.
- 08-28: degradation progressed; WiFi cannot start at all (possibly a
  brownout-reset loop; bridge re-establishes within ms each pass) ->
  module offline, machine runs CLEAN because the disturbance source
  (radio) never comes up.

The module has degraded itself into the "dumb wire, no radio" arm of the
experiment ladder -- and the machine running clean in that arm points at
WiFi power draw on the shared rail, not the data path and not firmware.

Confirmation + fix in one step (unchanged, USB split-power): feed the
XIAO from a USB-C charger. Expected: WiFi returns AND E5 stays away.
If E5 returns with WiFi on USB power, this story is falsified and the
shifter/analog branch reopens.

Interim state: machine usable from the panel; no web UI / HA / logging
until the module gets USB power.

## Update 2026-08-28 (USB split-power attempt): back-feed invalidates the test

Kai fed the XIAO from USB (PC) with the machine open. Result: ESP alive on
WiFi (1.17.8), link PERFECT (2381 frames, 0 bad checksums), but the panel
still shows E5 and the controller reports st=0xC2.

WHY THE TEST DID NOT RUN: the split was never achieved. wiring.md is
explicit -- "controller pin 4 (+5 V) = panel pin 4 = converter HV = XIAO
5V, one net". USB VBUS therefore back-feeds the machine logic rail through
the XIAO 5V pad. PROVEN: with the Shelly at 0.0 W (mains fully off) the
controller kept emitting B>P frames every 200 ms -- the controller and
panel MCUs were running on USB power.

Consequences:
- The Shelly can no longer reset the controller/panel while USB is
  plugged, so the E5 latch CANNOT be cleared and every "power cycle" is a
  brownout dip (loads drop, logic stays up) -- itself a good way to INDUCE
  a fault. st was observed going 0x82 -> 0xC2 across one such dip.
- All boot-latch results taken in this configuration are void.
- st=0xC2 = 0x40 latch + 0x82 lid-open (machine is physically open;
  0x82 is expected while the lid is off and is NOT a fault).

REQUIRED to actually run the experiment: disconnect ONLY the wire from the
CN2 pin-4 (+5 V) net to the XIAO **5V pad**. Keep everything else --
converter HV stays on the machine 5 V net, GND common, all four signal
lines. Then the XIAO is USB-only, the machine is Shelly-controlled, and no
back-feed exists.

That cut is simultaneously the decisive TEST and the candidate FIX: it
removes the module inrush/WiFi load from the machine 5 V rail at boot,
which is the surviving hypothesis for the t~5.1 s latch.

## Update 2026-08-28 (evening): WiFi ELIMINATED — radio-off test with serial telemetry

New tooling (fw 1.18.3): a **USB serial console** plus an NVS `nowifi`
mode that skips net/web/kasa entirely. This finally decoupled telemetry
from the radio, which had been the last unexonerated load. Console keys:
`s` status, `m` 1 Hz monitor, `c` CPU relay, `w` wire, `e`/`E` E5 mask
on/off, `r` reboot, `W`/`X` radio on/off, `?` help. Flash over USB with
`pio run -e c3 -t upload --upload-port /dev/ttyACM0` -- no OTA needed.

RESULT: with the radio completely dark, the controller STILL latches.
Captured at 1 Hz over serial, twice:

    t=40s  A2 16 00 82 04 00 03 31   clean boot, NO latch
    t=41s  A2 16 00 82 04 0C 03 3D   byte5 settles 0x00 -> 0x0C
    t=45s  A2 16 00 C2 04 0C 03 7D   bit 6 set -- exactly 5 s later
           bad_c frozen at 54 across the whole window: ZERO bad frames

**WiFi power draw and RF are therefore NOT the E5 trigger.** The theory
that survived three days is dead, and with it the whole rail-load branch
as far as the radio is concerned.

Confirmed structure of the fault: the controller boots CLEAN, communicates
perfectly for 5 s, then raises bit 6 with no corrupted frame anywhere in
between. It is a timed decision, not a reaction to bad data.

Byte 5 is the earliest divergence and now looks like a state code, not a
bitfield: 0x09 healthy idle, 0x0A on the 2026-08-26 latch (lid closed),
0x0C today (lid open, machine on the bench). Still undecoded, but it
settles ~1 s after boot -- 4 s BEFORE the status bit -- so whatever the
controller decides, it decides early.

Also established today:
- The 5 V wire removal DID isolate the controller: during a mains cut its
  line goes to noise (bad frames, ~500 byte/s of garbage) and ok_c freezes,
  i.e. the controller is genuinely unpowered. The PANEL stays up on USB.
- Therefore the panel no longer resets with the machine, so its own E5
  latch cannot be cleared by the Shelly. Clearing it needs mains off AND
  USB unplugged together.
- Bit 6 can only be masked in CPU relay mode. In wire mode the pad bridge
  means no byte passes through software and the E5 filter is inert however
  it is set -- worth knowing before trusting `e5f_mode=2`.

Open at the end of the session: the machine reads 0.0 W on the Shelly with
the outlet ON (standby was 1.4-1.8 W), i.e. it is not receiving mains --
a physical matter with the unit open on the bench.

Remaining ranked experiments: unchanged, minus WiFi. The fault is a
5-second timed decision by the controller that only occurs with the module
electrically inline, so the next evidence must come from a meter or a
scope on the CN2 lines, not from firmware.

## 2026-08-28 (night): ROOT CAUSE FOUND — the ESP->controller TX channel is open

Kai ran the clean A/B: CN2 back to the controller with the ESP entirely
removed -> NO E5, machine works. ESP back inline -> E5. The module is the
cause, as every earlier test implied. `/api/pinprobe` then localised it to
a single channel, reproducibly (4 probes, 2 rounds):

    GPIO6 -> CONTROLLER   pullup=1 pulldown=0 drive=1/0   external pull-up MISSING
    GPIO3 -> PANEL        pullup=1 pulldown=1 drive=1/0   external pull-up PRESENT

Both pads drive and read back their own level (edges 200/200), so the ESP
is fine. The difference is entirely external, and the panel channel is the
built-in control: same board, same probe, opposite result.

`pulldown` is the discriminating measurement. With the pad's INTERNAL
pull-down (~45k) enabled, a healthy channel still reads HIGH because the
shifter's 10k pull-up wins. The controller channel reads LOW -> no external
pull-up is present on that LV net -> that channel is open or unpowered.

Consequence, and it explains every observation of the last three days:
the ESP can pull the controller's RX line low through the MOSFET body diode
but cannot return it high, so the controller receives nothing usable. It
declares panel starvation ~5 s after boot and raises bit 6 -- which is
exactly the unit-1 semantics of that bit, and exactly the 5 s timing
captured over serial. Meanwhile:

- the ESP RECEIVES both directions perfectly (bad=0) -- RX paths are
  independent of this break, which is why every capture looked healthy;
- the bare machine works -- the panel drives the controller directly and
  the shifter is not in the path at all;
- wire mode, CPU relay, the minimal image and radio-off were all
  irrelevant, because the break is on the FAR side of the ESP pad. Every
  software experiment was testing the wrong side of the fault.

That is why the firmware could never be made to fix it, and why the fault
appeared after Wednesday's heavy cycle testing -- heat and vibration on a
solder joint or a wire.

THE FIX (hardware, one connection): repair the path from XIAO **GPIO6** to
the controller's CN2 **pin 2** (its RX input) -- the converter LV pad wire,
that channel's pull-up/solder joints, and the HV wire out to pin 2. Verify
with `POST /api/pinprobe?pin=6`: it must report "pin drives and reads back;
shifter pull-up present", matching GPIO3. A 10k from that LV net to 3V3
restores the pull-up if the resistor/joint is the failure; an open wire
needs re-making.

Diagnostic lesson worth keeping: we could see everything the module
RECEIVED and nothing it TRANSMITTED, so a broken transmit path presented
as a perfect link. `/api/pinprobe` -- comparing a suspect channel against a
known-good one on the same board -- is the tool that closed it, and should
be the FIRST thing run whenever both ends complain while the captures look
clean.

### Detect confirms the map, and narrows the fault to GPIO6 (2026-08-28 night)

`GET /api/detect` (passive edge counting, independent of config.h and of
wiring.md):

    edge counts   GPIO5=136   GPIO4=66   GPIO3=0   GPIO6=0
    rx_ctrl=5  rx_panel=4   tx stubs = {6, 3}

The two DRIVEN stubs are GPIO5 (controller output, 8-byte frames) and
GPIO4 (panel output, 5-byte frames) -- the 136:66 ratio matches 8-byte vs
5-byte frames at the same 5 Hz. GPIO3 and GPIO6 carry ZERO edges, i.e.
they are the two device INPUTS. That is a third independent confirmation
of the map, after frame headers (A2 on GPIO5, AA on GPIO4) and the
no-corruption test (driving GPIO6 200 times leaves bad_p at 0).

Kai reports the module was never rewired, so wiring.md's table disagrees
with the copper. Measurement wins; the table is stale and should not be
used to trace this harness.

Which input is which: Kai reports the LID OVERRIDE still works during E5.
That override rewrites the controller->panel frame (cn2.cpp:886,
"what the panel will see"), which goes out on txp = GPIO3. So GPIO3 ->
panel input is CONFIRMED BY FUNCTION, and GPIO6 -> controller input
follows by elimination.

This makes the diagnosis airtight rather than inferred: GPIO3 is a
working input stub WITH its shifter pull-up; GPIO6 is the other input
stub WITHOUT one. A connected channel presents ~10k from the ESP pad to
3V3. GPIO6 presents none, so that net is open.

Note the disproof of the "D4 goes to panel pin 2" reading: GPIO6 shows
ZERO edges. The panel transmits 5 frames/s, so anything on the panel's TX
output would show ~66 edges like GPIO4 does. GPIO6 sees nothing at all.

SHARPEST MEASUREMENT (no channel labels needed, power off):
measure resistance from the XIAO **D4/GPIO6 pad to 3V3**, then from
**D1/GPIO3 pad to 3V3** as the reference. Good channel ~10k; the faulty
one reads open. That one comparison localises the break.

## 2026-08-28 (late): the LV (3V3) rail to the level converter is the fault

The pull-up probe CHANGED STATE during the session, which is what finally
identified the failing part:

    earlier tonight   GPIO3->PANEL  PRESENT     GPIO6->CONTROLLER  MISSING
    now               GPIO3->PANEL  MISSING     GPIO6->CONTROLLER  MISSING

Kai reports the lid override worked earlier tonight (visible on the panel
even while E5 was displayed) and does not work now. That matches the probe
exactly: the panel channel had its pull-up while the override worked, and
lost it when the override stopped working. Hardware does not change between
two identical probes -- the connection is intermittent, and it degraded
while the unit was being handled.

Both TX channels failing TOGETHER points at one shared node, not two broken
signal wires. The shared node is the converter LV rail: **XIAO 3V3 -> the
converter LV pin**.

Why that produces exactly this fault, on a BSS138-style shifter whose gates
are tied to the LV rail:

- LV rail dead -> every MOSFET gate sits at 0 V -> the transistor never turns
  on, so the ESP->device direction is dead. Only the body diode conducts, so
  our LOWS still reach the far side and our HIGHS never do. Both the panel
  and the controller therefore receive broken data and each raises its own
  comms fault -- panel shows E5, controller sets bit 6 five seconds after
  boot.
- device->ESP still works, because the Arduino UART enables the ESP32 pad
  pull-up on RX, so reception needs nothing from the converter. That is why
  every capture looked perfect: bad=0 in both directions, all week.
- the bare machine works because the converter is not in the path at all.
- the fault comes and goes with handling, which matches "it was working in
  the morning" and "lid override worked before, even on E5".

FIX: re-make the XIAO **3V3 -> converter LV** connection (and confirm the
converter GND pad is common with XIAO GND). No meter needed to verify:

    POST /api/pinprobe?pin=3
    POST /api/pinprobe?pin=6

Both must report "shifter pull-up present". Today they read MISSING, and a
healthy channel read PRESENT earlier tonight, so the test has a confirmed
positive control on this very board.

Software was never implicated: the transmitted frames are byte-perfect with
valid checksums, verified from the to_panel history
(A2 18 00 C2 04 0C 03 73 received -> A2 58 00 82 04 0C 03 73 sent with a
deliberate 88 C spoof and bit 6 stripped).

## 2026-08-29: firmware EXONERATED by full-history bisection

Kai asked for a revert. Three builds spanning the entire project were
flashed to the same hardware and power-cycled, with the machine on the
Shelly so the controller genuinely restarted each time:

| build  | what it is | result |
|---|---|---|
| 1.18.5 | current | latches, st=0xC2 |
| 1.14.1 | 2026-08-23, the build that ran a FULL cycle inline | latches, st=0xC2 |
| 1.0.0  | first public commit (9bae832), PLAIN RELAY -- no E5 filter, no wire mode, no rewriting of any kind | latches, st=0xC2 |

Every one latches within ~5 s of controller power-up with zero bad
checksums in either direction. **The firmware is not the cause, across its
entire history.** 1.0.0 in particular rewrites nothing at all, so there is
no software behaviour left to blame.

Combined with Kai's own A/B (module removed -> machine runs clean; module
back -> E5), the fault is the module's physical presence and nothing else.
No further firmware work can address it.

Also settled tonight, and worth not re-litigating:
- The ESP->panel path WORKS. The panel displays exactly what we transmit:
  it showed lid OPEN because the controller reports 0xC2 and we forwarded
  it faithfully, and the frame history confirms every emitted frame is
  byte-perfect with a valid checksum. Kai was right that the panel keeps
  updating lid state during E5 -- my "frozen panel" theory was wrong.
- The lid override works: 0xC2 -> 0x00 on the wire, checksum valid.
- A reported "st_fwd oscillation" was NOT real: it was the status JSON
  being sampled while the relay task updated the mirrors. The to_panel
  history shows a perfectly uniform stream. Read /api/hist, never the
  status mirrors, when the question is what actually went out.
- 1.14.1 boots into WIRE mode, where the E5 mask is inert (pad bridge, no
  byte passes through software) and it predates the setPins() fix, so
  switching it to CPU relay is a silent no-op. It is strictly worse than
  current firmware for running the machine.

Practical position: the machine runs correctly with the module removed.
Anything further on E5 needs bench instrumentation on the module itself,
not another firmware change.

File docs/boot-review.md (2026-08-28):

# Boot-path code review: why E5 latches at boot (Aug 27)

Requested as a code review; delivered as one, with the boot timeline audited
instruction-by-instruction and each stage marked with what it can and cannot
cause. The differential to explain: machine clean until Aug 26 15:31, E5 on
every module boot since 17:45, clean bare, latching behind a 20-line minimal
image.

## Timeline of a boot, with everything that executes

| t (approx) | what runs | reviewed finding |
|---|---|---|
| 0–300 ms | **ROM + 2nd-stage bootloader** — no app code | Pads GPIO4/5/6 are the C3's JTAG pins (MTMS/MTDI/MTCK) until the app claims them: internal ~45 k pulls (up on 4/6, down on 5) fight the shifter's 10 k pull-ups — worst case sags a line to ~2.7 V, still a valid HIGH. **Cannot pull a line low. Constant since day one — cannot explain a Wednesday-afternoon change.** |
| ~300 ms | `instantBridge()` — first app instructions | 15 register writes, geometry `in5→out3, in4→out6`, identical to the wireSet used through days of completed cycles. Verified conducting by edge counts. |
| ~1.5 s | `openPorts()` steals TX pads for the UARTs | Microsecond-scale glitch, then wire-pref decides re-bridge. **Irrelevant: the minimal image never steals the pads at all and still latches.** |
| 2 s → | relay/apps | **Irrelevant: absent from the minimal image.** |

## The exoneration ladder (each rung tested, not argued)

1. firmware logic — minimal image (bridge+WiFi+OTA, no logic in path): latches
2. firmware size/boot speed — 23 % smaller, zero-init: latches
3. every firmware version incl. same-day-working 1.16.3: latches
4. NVS state — full wipe to virgin: latches
5. wire vs CPU mode, masks, pin map (re-verified), GPIO10 relay drive (gated),
   cut lengths 5 s–10 min: latches
6. bytes on the wire — frame-level diff vs working log: identical
7. bare machine, no module: **clean**

## Verdict

Within the reviewable code there is no remaining instruction that executes
before or at the latch moment in the minimal case — the entire program fits
on one screen and touches the link only through six register writes whose
geometry carried days of complete wash cycles. The ROM stage is constant
silicon. **The failure differential (working 15:31 → broken 17:45, module-in
vs module-out) is not reachable by any code path**, and the honest remaining
suspects are physical: something in the module↔controller electrical path
changed that Wednesday afternoon (a component stressed during the heavy
cycle testing — the BSS138 channel, a solder joint, the CN2 connector
seating), below the resolution of every probe the firmware can host.

Decisive instruments remaining: (1) USB-power split test — ESP powered
independently, bridge continuous across machine boots — separates the ROM
dark-window hypothesis from analog presence; (2) a multimeter on the shifter
HV pins during a latch. Software's file on this bug is closed.

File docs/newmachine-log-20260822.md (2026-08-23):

# Second D8 unit — session log, 2026-08-22

A day spent on an `E5` that turned out not to be ours, on a machine that is not
the one every assumption in this repo was built from. Written down because most
of it is a record of being wrong, and the wrong turns are the useful part.

## The machine

A later Momcozy D8 than the one this project was developed on: **touch panel**,
controller **byte 6 = `0x03`** where the original reads `0x02`. Same CN2 link —
9600 8N1, same frame layout, same load bitmap, same five fill targets. The
firmware ran it unmodified.

## The mistake that shaped the whole day

**`E5` was read as "communication failure" because that is what the BW05 manual
says — and the BW05 manual is the *other* machine's.**

Everything followed from that. A comms label sent me hunting comms causes: boot
blackouts, frame timing, GPIO pins, WiFi stalls, level-shifter channels. Each
was a plausible answer to a question that was probably never being asked. On a
link with **zero bad checksums in either direction all day**, "communication
failure" was the one explanation the evidence already excluded, and I kept
reaching for it anyway.

⚠️ **Do not assume an error-code table transfers between revisions.**

## What was proven about status bit 6

Measured on firmware **1.2.0, a plain relay with no rewriting at all**
(`st_real` identical to `st_fwd`), cold machine at 24 °C, panel idle, nothing
commanded:

```
t = 0–45 s   byte3 = 0x00   222 frames, clean
t = 45 s     byte3 = 0x40   raised, and held
```

The controller asserts it **by itself**. Ruled out, each by test rather than
argument:

| candidate | how it died |
|---|---|
| our firmware | bisected across 1.2.0 / 1.3.0 / 1.4.0 / 1.5.0 / 1.6.0 — all clean on a cold boot; then fully reverted to 1.2.0 and it still appeared |
| our rewriting | plain relay, forwarded byte byte-identical to received |
| temperature | appeared at 24 °C |
| link quality | 0 bad checksums both directions, byte-exact forwarding, all day |
| standing water | 30 s drain changed nothing |
| power-cycle duration | 1 s, 2 s, 8 s, 10 s — identical |
| heater stuck on | machine cools at the same rate powered and unpowered |

**The panel is what acts on it.** Captured at 5 Hz with no filtering:

```
284.4  A2 2C 00 00 …  AA 05 00 00 AF   wash + heat, healthy
295.4  A2 2C 00 40 …  AA 05 00 00 AF   controller raises bit 6
295.6  A2 2C 00 40 …  AA 00 00 00 AA   panel drops every load, 0.2 s later
```

That 0.2 s is the whole mechanism: the controller flags, the panel aborts. So
masking the bit stops the abort — which is a workaround on a fault nobody
understands, not a fix.

## Differences from the original unit

⚠️ **Both boards are the SAME revision.** Photographed and compared:
`BBW04001-UL-P`, `QM-V7 20250805`, `CEM-1 KB-5150 JZ-C E330831` on both — only
the QC stamp differs (2026.1.25 vs 2026.1.1), and the *later* machine's board
was tested three weeks *earlier*. So none of the differences below are hardware
differences. What differs is the panel, and whatever program the MCU runs.

| | early (button panel) | later (touch panel) |
|---|---|---|
| controller byte 6 | `0x02` | `0x03` — **not** a revision marker; see below |
| wash pump on `b0` | low-side switch never closes — needs the external relay | **works** |
| lid bits 1 and 7 | reported normally | **never seen set** in any capture |
| status bit 6 | only when starved of panel frames | also asserts spontaneously and holds |
| drain stage | 20 s | 28 s |
| fill rate | 2.24 counts/s | ~1.65 counts/s |

**`b0` working here means the relay mod is unnecessary on this revision.** Check
before wiring one.

## Things I broke, and what they cost

- **Masked the machine's own fault reporting.** Decided bit 6 was false and
  deleted it. That hid information and left an appliance that looked healthy and
  silently refused to work. Worst call of the day.
- **Masked it with a stale checksum.** Cleared bit 6 from byte 3 without
  recomputing the trailing XOR, because the recompute keyed off an *enumerated*
  list of overrides that the new one had not joined. Every masked frame was
  discarded by the panel — I caused a genuine communication failure while
  claiming to suppress a fake one.
- **A fill-stall guard that latched.** It stripped the intake bit and never gave
  it back, so for several minutes *I* was the thing stopping the machine.
- **Eight firmware flashes**, each starving the panel ~10 s and re-latching E5,
  each costing the owner a power cycle. Six times I called something fixed.
- **Called a transient a bug.** Reported the drain override "evaporating" off one
  sample; it held for 12 s on a careful retest.

## Things worth keeping

- **Checksums are now recomputed on observed change** (`out != b`), not from a
  list of features that goes stale the next time someone adds a rewrite.
- **Frame position is counted, not timed.** A 96 ms CPU stall during WiFi
  association made the relay drain the FIFO late, the byte gap looked like a
  frame boundary, and the index reset *mid-frame* — so byte 3 was never
  recognised and every position-keyed rewrite silently skipped it.
- **Emitted frames are checksum-checked** (`tx_bad`). Nothing was watching that
  direction; `ok_c`/`ok_p` only ever counted what we *receive*, which is why a
  corrupt-output bug survived a flash, a smoke test and my own inspection.
- **`tools/selftest.py`** — reports "not measurable" for loads with no sensor
  instead of claiming a pass.
- **The OTA gap is measured** across the reboot via the RTC clock: ~9.8 s, well
  past the panel's tolerance. An `E5` after any flash is the update, not a fault.

## Still unexplained

- What bit 6 means on this controller, and what makes it fire ~45 s after a cold
  boot with nothing running.
- Why the intake pump ran twice on command (0→36, 0→54 counts) and then stopped
  responding to the byte-identical frame for hours.
- Why the level-shifter pull-up on **`GPIO6`** — the transmit line to the
  controller — read present in the morning and absent by evening, 8/8 both times.
  It should not matter (the UART drives push-pull) but it changed, and it is on
  the one path we cannot observe.

## Controlled heat tests, 2026-08-23

Driven directly from the ESP32 with the panel held idle, bounded and monitored,
mains ready to cut. Every one ran **clean — no lockout**.

| stage | water | heat rate | lockout |
|---|---|---|---|
| wash + heat | 20 counts | **+0.2022 °C/s** | no |
| wash + heat | 80 counts | **+0.0801 °C/s** | no |
| steam (heater, no circulation) | 20 counts | **+0.3466 °C/s** | no |
| **dry (air heat + blower)** | empty | **−0.0501 °C/s** | no |

What these kill and what they leave standing:

- **Heat rate does not determine the lockout.** The 80-count run held 0.0801 °C/s
  and finished clean; cycle 3 locked out at 0.077 °C/s. Same rate, opposite
  outcome, and this run went straight through 44 °C.
- **The water heater is sound at every volume tested**, and the sump probe
  tracks it faithfully. Both of the day's earlier theories — dead element, stuck
  sensor — are dead.
- **Steam is the fastest of all** (0.35 vs 0.20 at the same volume). Without
  circulation the heat concentrates near the probe rather than spreading.
- ⚠️ **Dry can never satisfy a "heater on → temperature must rise" check.**
  With the air heater and blower running, the sump reads a steady *decline*.
  That is physics, not a fault: the blower cools the sump, the air heater warms
  air, and this machine has **only the sump NTC — there is no air probe**. Four
  of the six observed lockouts began during dry.
- Cutting the heater at 72 °C let the sump coast on to **83 °C** — an 11 °C
  overshoot. The element runs far hotter than the water and sheds heat slowly.

⚠️ **The lockout needs a LONG power-down to clear.** Measured directly: 15 s,
30 s and 45 s all came back locked; **60 s cleared it**. Quick flicks do not
work, which is why several earlier "power cycle didn't help" observations were
misleading.

⚠️ **A masked bit 6 does not unlock the controller.** Masking stops the *panel*
aborting; the controller still ignores every load command while locked. The
machine only runs if bit 6 is clear *when the cycle starts*.

## The test never run

**Unplug the module; connect the panel straight to the controller's `CN2`
header.** It is the only measurement that separates *the machine* from *the
thing plugged into the machine*, and no amount of instrumenting from inside the
link can substitute for it.

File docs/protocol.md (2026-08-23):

# CN2 protocol

**9600 baud, 8N1, 5 V logic, LSB-first, no parity, one stop bit, both lines idle
HIGH, XOR checksum.**

Decoded on **one machine** — a Momcozy D8 (`BW05`), controller board
`BBW04001-UL-P` — with an ESP32-C3 as a transparent man-in-the-middle, across
full wash, self-clean and storage cycles.

⚠️ **Nothing here has been checked against a second machine.** The physical layer
and framing are the parts most likely to carry over; the **load and status bit
meanings are this controller's firmware** and should be treated as unverified
anywhere else. Confirm each one by watching the load act before you rely on it.

**The panel is the command authority; the controller executes.** The panel runs its
whole UI locally and transmits a bitmap of which loads to energise plus a fill
target. The controller drives them and reports its own state back. It gates
**nothing except the intake motor**. Invert that assumption or none of this reads
correctly.

Not fully decoded: controller byte 5, panel byte 2's top bit, status bit 0, panel
b6/b7, and how the panel starts a cycle. None of that blocks normal use — the
ESP32 runs cycles itself rather than asking the panel to.

## Every bit, at a glance

```
 PANEL -> CONTROLLER    AA  b1  b2  b3  xor
                            |   |   `- FILL TARGET
                            |   `----- determined by b3, no independent info
                            LOAD CONTROL BITMAP

 CONTROLLER -> PANEL    A2  T   F   S   04  ??  02  xor
                            |   |   |       `- unknown, 5..14 — NOT a temperature
                            |   |   `- STATUS BITFIELD
                            |   `----- FLOW-METER PULSE COUNT
                            `--------- TEMPERATURE (uncalibrated)
```

| Bit | Panel byte 1 — **energise** | Controller byte 3 — **state** |
|---|---|---|
| 0 | ⚠️ **wash pump** 24 V — unconfirmed | ⚠️ **flow-related, unresolved** |
| 1 | ✅ **drain** | ✅ **lid reed/magnet** |
| 2 | ✅ **water heater** 110 V | ✅ **`E3` Sensor Open Circuit** |
| 3 | ✅ **air heater** 110 V | ✅ **`E4` Sensor Short Circuit** |
| 4 | ✅ **dry — blower + heater** | ✅ **`E0` Voltage Anomaly** |
| 5 | ✅ **intake motor** (gated) | ✅ **`E7` Fan Failure** (mid-cycle only) |
| 6 | ❌ never seen set | ✅ **`E5` Communication Failure** |
| 7 | ❌ never seen set | ✅ **lid micro switch** |

⚠️ **Almost nothing is gated.** `b1`–`b4` drive their loads directly — heaters fire
with no cycle, no water, lid open. `b5` needs a non-zero fill target in byte 3 and
does nothing without one; that is the only gate we can demonstrate. See
[safety.md](safety.md).

## Physical layer

| Property | Value | How |
|---|---|---|
| Baud | **9600** | narrowest pulse 103.68 µs → 9645 est, +0.5 % |
| Format | **8N1**, LSB-first | 10 bit-times per frame |
| Logic level | **5 V** (measured 5.13 V high) | ⇒ a 3.3 V MCU **needs** level shifting |
| Idle | **HIGH**, both lines | ordinary UART |
| Checksum | **XOR** of all preceding bytes | below |

### The checksum is XOR, not sum

The controller frame proves it; the panel's idle frame cannot, because every
payload byte is `00` and it satisfies both rules.

```
A2 ^ 18 ^ 00 ^ 42 ^ 04 ^ 0E ^ 02  =  F0    ✔ matches
A2 + 18 + 00 + 42 + 04 + 0E + 02  =  0x16  ✘
```

**If your capture contains only all-zero payloads you cannot tell sum from XOR.**

## Pin map

| CN2 pin | Frame | Len | Header | Direction |
|---|---|---|---|---|
| **1** | `A2 23 00 02 04 0D 02 88` | 8 | `0xA2` | **controller → panel** ✅ measured |
| **2** | `AA 00 00 00 AA` | 5 | `0xAA` | **panel → controller** ✅ measured |
| 3 | — | — | — | `GND` |
| 4 | — | — | — | `+5V` |

Measured, not inferred: overrides on the pin-1 stream change what the *panel
displays*; overrides on pin 2 change what the *controller does*.

**Say `controller→panel` / `panel→controller`, never "RX"/"TX"** — the controller's
TX is the panel's RX is the ESP32's RX.

## Timing — independent broadcasts, NOT request/response

| | Period (median) |
|---|---|
| controller → panel | **200.00 ms** |
| panel → controller | **201.00 ms** |

Each side transmits on its own clock and neither waits for the other. The 1 ms
difference slides the phase continuously — across one 25 s capture the panel's
offset drifted **0 → 99 ms** smoothly. Any "reply latency" is just phase: it read
28, 32, 41 and 49 ms on successive attempts, and each time looked like a response
delay.

**To impersonate the panel, just transmit every ~200 ms.** There is no poll to answer.

## Framing

Delimited by **header + length**, never by idle gap: `0xA2` → 8 bytes, `0xAA` → 5.

Gap delimiting fails under preemption — timestamps come from when the task *reads*
a byte, and task gaps of 7–8 ms against a ~3.6 ms threshold chopped frames into
phantom changes.

### ⚠️ A valid checksum is not proof of alignment

The idle frame `AA 00 00 00 AA` is self-similar. Start one byte late:

```
AA 00 00 00 AA | AA 00 00 00 AA        the real stream
            ^-- start here
   ->  [AA, AA, 00, 00, 00]            XOR = 0x00, so it VALIDATES
```

It re-locks identically every frame. **Observed live: 386 consecutive
checksum-valid frames reporting byte 1 = `0xAA`** — drain + air heater + intake on
an idle machine — with `bad_p` at zero throughout.

Fix: **gap-based resync**, not gap-based delimiting. Frames are ~200 ms apart and
five bytes take ~5 ms, so a >20 ms inter-byte gap is unambiguously a boundary and
resets the assembler. Length still decides where a frame *ends*.

---

# Controller → panel — 8 bytes, header `0xA2`

```
  A2  23  00  02  04  0D  02  88
  |   |   |   |   |   |   |   `- XOR of bytes 0..6
  |   |   |   |   |   |   `----- 0x02 on one machine, 0x03 on the other.
  |   |   |   |   |   |           NOT a board revision: both boards were
  |   |   |   |   |   |           photographed and carry the SAME part number
  |   |   |   |   |   |           BBW04001-UL-P, the same revision QM-V7
  |   |   |   |   |   |           20250805 and the same laminate markings --
  |   |   |   |   |   |           only the QC date differs (2026.1.25 vs
  |   |   |   |   |   |           2026.1.1). Same hardware, different value, so
  |   |   |   |   |   |           it identifies something the BOARD does not:
  |   |   |   |   |   |           model variant, panel type, or MCU firmware
  |   |   |   |   |   |           build. Unresolved.
  |   |   |   |   |   `--------- unknown, 5..14 — NOT a temperature
  |   |   |   |   `------------- constant 0x04, unknown
  |   |   |   `----------------- STATUS BITFIELD
  |   |   `--------------------- FLOW-METER PULSE COUNT
  |   `------------------------- TEMPERATURE, rises with heating
  `----------------------------- header
```

## Status byte — byte 3

Seven bits identified, **bit 0 is not**. Bits 2–6 are a **fault register**; they
read zero across the archive because nothing has ever failed on this machine, and
were mapped by injecting each and reading the panel.

| Bit | Mask | Meaning |
|---|---|---|
| 0 | `0x01` | ⚠️ **UNRESOLVED, flow-related** — [below](#bit-0--flow-related-unresolved) |
| 1 | `0x02` | **lid reed/magnet** |
| 2 | `0x04` | **`E3` Sensor Open Circuit** |
| 3 | `0x08` | **`E4` Sensor Short Circuit** |
| 4 | `0x10` | **`E0` Voltage Anomaly** |
| 5 | `0x20` | **`E7` Fan Failure** — only mid-cycle |
| 6 | `0x40` | **`E5` Communication Failure** |
| 7 | `0x80` | **lid micro switch** |

Observed values: `0x00` `0x01` `0x02` `0x03` `0x42` `0x04` `0x0B` `0x80` `0x85`.

**A bitmask, not a code field.** Sending `0x0C` (bits 2+3) displayed `E3`, not a
third code — independent flags, and the panel shows the **lowest set bit**.

### ⚠️ Fault bits latch

One frame is enough, and it holds until the machine is power-cycled. Clearing the
bit does not clear the display.

**A single corrupted frame with bit 2 set would strand the panel in `E3` until a
power cycle.** The XOR checksum is the only thing between a noisy wire and a
permanent false fault — the strongest argument here for level shifters and for
watching `bad_c`/`bad_p`. It also means the relay must never emit a malformed
frame toward the panel.

### The panel does not range-check the temperature

Forcing byte 1 to `0x00` or `0xFF` does **not** provoke `E3`/`E4`. The controller
is wired to the thermistor, does the range check itself and reports a verdict in a
bit; the panel only ever sees a number. That is the shape of the whole protocol —
the controller reports *hardware* faults as flags, everything else is the panel's
inference.

### Bit 5 is context-dependent

Set on an **idle** panel it does nothing. Set while a **cycle runs**, the same bit
displays `E7`. It fired while the fan was *not* running (the panel was commanding
`drain+intake`), so the gate is "a cycle is active", not "the fan is active".

Worth remembering for the two codes still unaccounted for: a bit can look dead
purely because everything was tested at idle.

### `E0` is reachable, and it points at byte 5

`E0` is bit 4, raised by the controller — so **the controller measures mains
voltage**, which gives byte 5 its first real candidate. Byte 5 sits at 10–11, sags
to 9 under sustained blower load, reads highest when nothing runs, has no
correlation with temperature (r = −0.065), and during a power-down went to `0x00`
for the only time on record:

```
A2 15 00 82 04 00 02 33     checksum valid, byte 5 = 0x00
```

At ~10 V per count, 11–12 is 110–120 V and 9 is a sag. Still a hypothesis: `0x05`
held for 1212 s during an idle period does not fit, and per-load means are not
cleanly monotonic.

### `E1` and `E6` have no bit

**`E1` is not raised by a stalled flow count.** Given zero flow for **330 s while
the intake motor was commanded** — 8× a normal 40 s fill — the panel produced no
error, no alert, no timeout. It simply waited.

⚠️ **Neither end has a fill timeout.** If the flow meter fails while water still
flows, the count never reaches target and the intake motor runs indefinitely into
a machine that keeps filling. See [safety.md](safety.md).

The manual's **Water Shortage** alert is *"insufficient water in the tank"* — the
removable reservoir, not the sump — and recovers by refilling and pressing
Start/Pause, unlike the latching hard faults. The board has one unexplained input
that would suit it: `SW1`, a black 3-pin connector on a machine with a removable
tank. Unproven, but the only candidate.

## Bit 6 — comms fault on one unit, something else on the other ⚠️

On the early unit bit 6 behaves exactly as the manual's `E5` implies: starve
the controller of panel frames and it raises the bit within ~8 s, feed it again
and it clears.

On the **later touch-panel unit** it does that too — *and* asserts
spontaneously. Observed over a full day:

- raised with **zero bad checksums in either direction**, byte-exact forwarding,
  and the panel provably receiving (a forged lid state changed its display)
- held for **hours**, surviving power cycles of every duration
- unaffected by draining the tub, by cooling, or by firmware version — bisected
  across five builds, every one clean on a cold boot
- no precursor: every other byte the controller sends is unchanged across the
  transition
- the **panel** is what acts on it — measured at 5 Hz, the controller set the
  bit and the panel dropped every load 0.2 s later

It also appeared the instant a dry stage ended, then held while the controller
ran its storage phase autonomously with the panel commanding nothing.

⚠️ **Do not read `E5` as "communication failure" on this unit.** The code table
is the early unit's (`BW05` manual, p.29) and may not transfer. A link that is
provably clean while the panel shows a comms error means the label is wrong,
not the link.

`POST /api/e5filter` can mask the bit so the panel stops aborting. It removes
whatever protection the bit represents, so the firmware pairs it with a heater
ceiling — see [api.md](api.md).

## Bit 0 — flow-related, UNRESOLVED

Two experiments disagree and neither reading survives both. **Do not rely on this
bit, and do not use it as a dry-run alarm.** A flow counter frozen for 5.7 s under
commanded intake did *not* set it, but a fill released short of its target blipped
it for a single frame. The archive's 5 occurrences are all release-edge transients.

Treat it as unmapped.

## The lid has TWO switches — bits 1 and 7

Bit 1 is a reed/magnet sensor, bit 7 a micro switch, and the machine treats the lid
as closed only when **both** are triggered — one detects the lid present, the other
that it is latched.

They change at **different moments** as the lid is handled, which is what two
switches with different actuation points look like; a single sensor reported twice
would move together.

⚠️ **`b7`'s polarity is not settled.** `b1` is: the lid was removed and refitted and
the bit round-tripped `0x00 → 0x02 → 0x00`, so **b1 set = lid off**. For `b7` the
machine washed 2209 s in `b1=0,b7=0` and 3354 s in `b1=0,b7=1` — either reading
fits. To settle it, open the lid slowly and watch both bits live on `/dev`.

> ⚠️ Bit 1 was first read as "idle/ready" because the machine sat open for a whole
> session, so `0x02` appeared in every idle capture — a confounded variable, and
> `0x42` looked like a compound error code when it was only *lid off* plus *E5*.
> **Vary one condition at a time and round-trip it.** A bit that returns to its
> exact previous value is real; one that only ever changes in one direction may be
> a sensor drifting.

## `E5` is symmetric — and latched

The controller sets bit 6 when the panel goes quiet (measured), but unplug the CN2
cable and the panel displays `E5` with no data arriving at all. It is a **symmetric
watchdog**: each side independently flags the other's silence. So:

1. Clearing bit 6 in the forwarded frame hides `E5` only when the link is otherwise
   healthy. It cannot suppress the panel's own detection of a dead link.
2. **`E5` alone does not tell you which end lost the link** — see
   [troubleshooting.md](troubleshooting.md).

The panel **latches** it: once restored, the display keeps showing `E5` until
power-cycled, matching the manual's only advice — *"Power off and restart."*

**Judge the link by byte 3, not by the display.** Byte 3 is live; the display is not.

---

# Panel → controller — 5 bytes, header `0xAA`

```
  AA  20  40  20  EA
  |   |   |   |   `- XOR of bytes 0..3
  |   |   |   `----- FILL TARGET
  |   |   `--------- determined by byte 3
  |   `------------- LOAD CONTROL BITMAP
  `----------------- header
```

Idle is `AA 00 00 00 AA`.

## Byte 1 — the load control bitmap

Each bit commands one load. Setting it in the relayed frame energises that load on
a real machine; clearing it de-energises it. Every identified bit was confirmed by
forcing it and watching the physical load — direct actuation, not inference.

| Bit | Mask | Load | Connector | Gated? |
|---|---|---|---|---|
| 0 | `0x01` | ⚠️ **wash pump** 24 V — never confirmed | `WS PUMP` | ? |
| 1 | `0x02` | **drain** | `PUMP` (AC `PSB-1`) | no |
| 2 | `0x04` | **water heater**, 110 V AC | relay | no |
| 3 | `0x08` | **air heater**, 110 V AC | relay, red connector | no |
| 4 | `0x10` | **dry: blower + heater** | `− FG +` + heater | no |
| 5 | `0x20` | **intake motor** | `DC PUMP` | ⚠️ **yes — needs a fill target** |
| 6 | `0x40` | unknown — never set | — | — |
| 7 | `0x80` | unknown — never set | — | — |

Observed byte 1: `0x00 0x01 0x02 0x04 0x05 0x10 0x12 0x18 0x1A 0x20 0x22 0x24`.

`b4` is not a fan bit — it energises the blower *and* a heater, a dry-mode master.

**The 303.7 Ω sprayer valve is unattributed** and has never been commanded in any
captured cycle, and b6/b7 have never been seen set. The web UI omits them; they
stay reachable via `POST /api/panel_ovr`.

### b0 — assigned to the wash pump, never confirmed ⚠️

The heater is **not** interlocked behind the pump — all three combinations occur
across a full cycle.

b0 is assigned to the 24 V wash pump **by elimination and timing**: never commanded
before a fill (0 of 4,687 frames), never co-occurring with anything but the water
heater, and no other load fits.

⚠️ **The one confirming attempt failed.** Commanding b0 with a frame byte-identical
to the machine's own wash-phase frame — `AA 01 00 00 AB`, lid closed — does **not**
close the control board's low-side switch on the `WS PUMP` header. Board fault,
undiscovered gate, or b0 not being the pump: unresolved. The pump is now driven by
an external relay; see
[hardware.md](build.md#if-a-load-will-not-switch).

> ⚠️ A partial log of a 70-minute cycle supports almost any tidy story. Treat every
> "never observed" claim here as provisional until a full cycle has been seen end
> to end.

### The controller has no opinion about water

Held with `b5` set the intake motor runs **indefinitely** — no timeout, no
flow-based cutout, no error; 700 frames during a failed fill showed nothing
unusual. A full cycle commanded it 397 times and the counter advanced every time.

**`E1` is not a bit in the UART** — the panel raises it, from controller byte 2.
That is why a flow spoof has to be aimed at the panel, not the controller.

## Byte 3 — the fill target

| byte 3 | counts delivered | occurrences |
|---|---|---|
| `0x07` (7) | 20 | 1 |
| `0x1C` (28) | 80, 80 | 2 |
| `0x20` (32) | 90, 90, 90, 90 | 4 |
| `0x23` (35) | 100, 100 | 2 |
| `0xFF` (255) | 131, 121, 164 | 3 — sentinel, below |

```
byte3 = round(target_count * 0.35)
  20 -> 7.0 -> 0x07 ✅    80 -> 28.0 -> 0x1C ✅
  90 -> 31.5 -> 0x20 ✅   100 -> 35.0 -> 0x23 ✅
```

**Twelve fills, three cycles, four distinct targets, no exceptions**, and the count
follows the word across two different cycle programs — a commanded setpoint, not a
per-step constant. The fill is closed-loop: the panel says "35 units", the
controller counts flow pulses to 100 and releases the intake motor 1–2 s later.

**The controller enforces it itself.** With the panel fully overridden out of the
loop and the ESP32 holding `b5` with target `0x20`, the controller counted to 90
and **zeroed the counter by itself**. The counter reset is the controller
announcing the fill is finished, which makes it a far better completion signal than
arithmetic — inverting the formula lands ±1.4 counts, and `0x20` predicts 91 where
the machine delivers 90.

### `0xFF` is a sentinel — the cool-down rinse

The three `0xFF` fills delivered 131, 121 and 164 counts, no target honoured. It is
the **only** value appearing with `pb1 = 0x22` (drain + intake); every real target
appears with `pb1 = 0x20`.

It is **not** "empty the tank": `pb1` holds `0x22` continuously, never pulsed, and
the flow counter climbs steadily at ~2.2 counts/s, so fresh water is pumped *in*
the whole time the drain is open. It is **cooling the machine before the dryer**:

```
washcycle    94 -> 69 -> 45 -> 36 -> 32 -> 31 -> 30 C   in 62 s
selfclean2   55 -> 54 -> 44 -> 35 -> 31 C
selfclean    56 -> 55 -> 49 -> 44 -> 43 -> 42 C
```

94 → 30 °C in a minute is cold mains water flooding a hot sump; a drain alone would
coast down. The sequence is identical every cycle: `0xFF` rinse → drain `0x00` →
dry. `0xFF` means *no volume target* because there cannot be one — water leaves as
fast as it arrives.

**What ends it is unproven.** All three end just after the temperature bottoms out
and starts rising, consistent with a sump running dry, but at different points:

| | minimum | at end |
|---|---|---|
| washcycle | 30 °C | 34 °C |
| selfclean2 | 31 °C | 37 °C |
| selfclean | 42 °C | 43 °C |

Temperature-linked rather than volumetric is as far as the evidence goes. Either
reading needs the same physical event — cold water no longer arriving, i.e. the
tank running dry — so on a machine fed from an always-on supply nothing ends it.
The firmware caps it at 180 s by default: [`POST /api/flushcap`](api.md).

## Byte 2 — carries no independent information ⚠️

Values `0x40`, `0xAB`, `0x2A`, `0xD6`, `0xFF`. Not a temperature (`0x40` preceded
stage peaks of 26, 24, 76, 74 and 58 °C), not a duration. It is **completely
determined by byte 3** — six distinct values each side, six distinct pairs,
strictly 1:1 across every captured frame.

Three of the four real values fit the same law one unit finer:

```
byte2 = floor(counts * 15/7)          byte3 = round(counts * 7/20)
  20 -> 42.9  -> 0x2A ✅                20 -> 0x07 ✅
  80 -> 171.4 -> 0xAB ✅                80 -> 0x1C ✅
 100 -> 214.3 -> 0xD6 ✅               100 -> 0x23 ✅
  90 -> 192.9 -> 0xC0 ❌               90 -> 0x20 ✅   observed 0x40
```

The mismatch differs by **exactly `0x80`** — bit 7 and nothing else. So byte 2 looks
like the same target at ~2.86× resolution with something riding in its top bit. One
outlier in four is a lead, not a conclusion: **a fifth distinct fill target settles
it**, and no captured cycle has produced one.

Practically: byte 2 is redundant. Read only byte 3.

## Cycle start sequence (steam, captured end to end)

```
   0.2  PANEL  AA 00 00 00 AA     idle
  36.0  PANEL  AA 02 00 00 A8     b1 DRAIN, no fill target yet
  56.8  PANEL  AA 20 40 20 EA     b5 intake + target 0x20 = 90 counts
  60.5  PANEL  AA 00 40 20 CA     loads clear
```

The drain step ~20 s ahead appears identically before the drying run — the machine
**clears the sump before it fills**, so every cycle starts with a drain even when dry.

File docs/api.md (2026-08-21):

# HTTP API

Everything the web UI does, it does through these. There is no state the page
holds that the device does not.

Base URL is the device: `http://baby-washer.local/` or its IP. `GET` returns JSON;
`POST` takes query-string arguments, never a body, and returns `{"ok":true,...}`.

**Hex arguments are hex without `0x`.** `clr=42` means `0x42`. The exceptions are
`/api/tempovr` and `/api/virtual`, which take decimal.

---

## Reading

| Endpoint | Returns |
|---|---|
| `GET /api/status` | Everything the UI polls: both raw frames, decoded fields, override state, counters |
| `GET /api/version` | Firmware version, build, MD5, partition, uptime, boot count, reset reason |
| `GET /api/frames` | Newest frames from the sniff ring, annotated with checksum candidates. `?n=` to limit | Rows are annotated `xor-ck` / `sum-ck` when the last byte matches a checksum over the preceding ones.
| `GET /api/hist` | Run-length frame history per direction: `ctrl`, `panel`, `to_panel`, `to_ctrl` |
| `GET /api/deltas` | Frames that differ from the captured idle baseline |
| `GET /api/graph` | 30 min of temperature (bit 7 = **water** heater) plus a parallel `air` lane (air heater or dry), and 60 s of flow |
| `GET /api/flowlog` | Every change of the flow count with a timestamp, `[[ms,count],...]` |
| `GET /api/detect` | Result of the last pin-map scan |

### Which fields to trust

`ctrl_raw`/`fb` and `panel_raw`/`fp` are the **raw frames** and are
authoritative. The decoded fields (`pb1`, `pb2`, `pb3`, `st_real`) come from the
same frame snapshot, so they agree — but if you are analysing traffic, parse the
raw hex and verify the XOR yourself.

`to_panel` and `to_ctrl` in `/api/hist` are what was **actually transmitted**
after any rewrite. When you are testing an override, read those, not `fb`/`fp`.

---

## Driving the machine

⚠️ These energise real loads. [safety.md](safety.md) first.

### `POST /api/panel_ovr?clr=<hex>&set=<hex>`

Rewrite byte 1 of the panel frame on its way to the controller:
`out = (b & ~clr) | set`. This is the load bitmap.

```
b0 wash pump 24 V     b1 drain            b2 water heater 110 V
b3 air heater 110 V   b4 dry blower+heat  b5 intake motor
```

**`b5` alone does nothing.** The intake motor is gated on a non-zero fill target
in byte 3 — see `/api/mode_ovr`. This is the only gate we can demonstrate;
`b1`–`b4` drive their loads directly.

⚠️ **`b0` is a live question.** Commanding it does not close the control board's
low-side switch on the `WS PUMP` header, so either the board is faulty, there is
a second gate nobody has found, or b0 is not the pump. The pump is driven by an
external relay instead.

`b6` and `b7` have **never been seen set**, so the web
UI omits them from its bit table. This endpoint still takes any mask, and forcing
them by hand is the only remaining way to hunt the unattributed 303.7 Ω sprayer
valve.

### `POST /api/mode_ovr?b2=<hex>&b3=<hex>`

Rewrite panel bytes 2 and 3. Empty arguments restore pass-through.

Byte 3 is the **fill target**: `byte3 = round(counts × 0.35)`. Byte 2 is
determined by byte 3 and carries no independent information.

| Pair | Counts | Where the machine uses it |
|---|---|---|
| `2a/07` | 20 | steam charge |
| `ab/1c` | 80 | rinse |
| `40/20` | 90 | wash |
| `d6/23` | 100 | self-clean |
| `ff/ff` | none | end-of-cycle cool-down flush, no target |

⚠️ `ff/ff` is a sentinel, not a volume. The machine only ever sends it with the
drain open, and **neither end has a fill timeout** — with the drain shut the
intake motor has nothing to stop it.

### `POST /api/press?mask=<hex>&ms=<n>`

OR `mask` into byte 1 for `ms` milliseconds, then release.

---

## Lying to the panel

Everything below rewrites the controller→panel direction. The machine itself is
unaffected; only what the panel believes changes.

### `POST /api/status_ovr?clr=<hex>&set=<hex>`

Rewrite status byte 3. This is the fault register:

| Bit | Mask | Effect on the panel |
|---|---|---|
| 0 | `01` | ⚠️ **flow-related, unresolved.** The controller sets it itself; a frozen counter under commanded intake does *not* set it, but a fill released short of its target blips it. See `protocol.md` |
| 1 | `02` | lid reed reads open |
| 2 | `04` | **`E3` Sensor Open Circuit** |
| 3 | `08` | **`E4` Sensor Short Circuit** |
| 4 | `10` | **`E0` Voltage Anomaly** |
| 5 | `20` | **`E7` Fan Failure** — only while a cycle is running |
| 6 | `40` | **`E5` Communication Failure** |
| 7 | `80` | lid micro reads open |

The web UI offers three presets on this: **hide E5** (`clr=40`), **hide faults**
(`clr=7C` — bits 2–6, every fault the controller can report) and **pass all**
(`clr=0&set=0`). The lid bits are deliberately excluded from "hide faults": they
are an interlock, not a fault, and hiding one of the two desynchronises them.

⚠️ **Every fault bit latches.** One frame is enough and the code holds until the
machine is power-cycled; clearing the bit does not clear the display. The panel
shows the **lowest set bit**.

### `POST /api/tempovr?v=<0..255>`

Force byte 1, the temperature the panel sees. `v=-1` or empty restores
pass-through.

This does **not** raise `E3` or `E4` — tested at `0x00` and `0xFF`, no reaction.
The controller reads the thermistor and reports a verdict in a status bit; the
panel only ever sees a number. Pinning it mid-rise while the heater is commanded
is the untested candidate for `E6`.

### `POST /api/flowspoof?v=on|off`

Hold the flow count the panel sees at zero. Only the starve direction exists —
faking the count upward would convince the machine it had filled when it had not.

Does not raise `E1`: tested with zero flow for 330 s while the intake motor was
commanded, and the panel waited without complaint.

### `POST /api/flushcap?ms=180000`

Bounds the untargeted cool-down flush (`pb1` intake bit set with byte 3 =
`0xFF`). Neither end of the link times one out — it ends when the water stops
arriving, which on a stock machine is the hand-filled tank running dry. The same
Self-Clean program was measured at **64.1 s** and at **114.6 s**. Feed the tank
from a float valve or any always-on supply and nothing ends it at all.

After `ms` the **intake** bit is stripped from the forwarded byte 1 and the
**drain** bit is left set, which reproduces the event the controller already
terminates on rather than inventing a new one: the sump empties, the temperature
rises, the cycle moves on.

Applied last, so it also bounds the cycle runner and a manual `b5` override —
both can hold the intake on indefinitely and neither is a reason to allow it.
Metered fills are untouched: they carry a real target and the controller ends
them itself on the flow count.

Default **180 s**, persisted to NVS. That is 1.6× the longest flush ever
observed and longer than the runner's own longest (116 s), so it cannot truncate
normal operation. `0` disables it — only safe on a hand-filled tank, which
bounds the flush by running dry.

Status carries `fcap_ms`, `flush_on`, `flush_ms`, `flush_cap` and `flush_n`.

### `POST /api/wsrelay?mode=off|on|auto[&pol=low|high][&pin=N]`

Drives the **external wash-pump relay**. The control board holds 24 V on the
`WS PUMP` header permanently and switches the low side, and that low-side switch
does not close when panel b0 is commanded — verified with a frame byte-identical
to the one the machine sends during its own wash phase. So the pump gets a relay
of its own.

| Mode | Behaviour |
|---|---|
| `auto` | Follow **b0 of the panel frame as forwarded**. Default. |
| `off` | Contacts held open whatever b0 does. |
| `on` | Forced closed. **Not persisted** — a reboot comes back in `auto`. |

`auto` is the mode that makes this transparent: it reads the *forwarded* byte, so
the machine's own cycles, the ESP32 cycle runner and any `panel_ovr` b0 write all
drive the pump without knowing the relay exists.

`pol` matches the module (`low` = the usual opto-isolated board, default).
`pin` moves it; both persist to NVS.

**Two limits, and they are the only protection there is** — the pump reports
nothing, so the firmware cannot tell whether it is turning:

- **30 min runtime cap.** Trips, latches open, and only rearms when the command
  drops. `wsr_lock` in `/api/status` shows it.
- **Panel-link watchdog.** No panel frame for 3 s and the contacts open, because
  in `auto` the command comes from a frame and stale b0 is worthless.

The relay is also opened before an OTA write, and on every boot before anything
can command it.

⚠️ **An external pull resistor is not optional.** Between reset and `cn2::begin()`
the pin is high-Z, and in safe mode it is never configured at all. 10 k to 3V3
for an active-low module, 10 k to GND for active-high. Without it a crash, a
reset or a boot loop can energise the pump.

### `POST /api/lid?v=on|off`

Force both lid bits together. The machine wants `b1` and `b7` both clear before
it treats the lid as shut, so moving one alone leaves it seeing half an open lid.

---

## Virtual controller — a panel test rig

### `POST /api/virtual?v=on|off[&auto=on|off][&temp=][&flow=][&st=][&b5=]`

Synthesise the controller→panel frame and drop the real controller's. The panel
sees a machine reporting whatever you set.

Turning it on also engages **PROBE**, and that is what makes it safe rather than
merely quiet: the real controller keeps receiving an idle panel frame, so it stays
synchronised and `E5`-free while being unable to receive a single command. Both
directions are neutralised.

`auto` runs a model of the machine from measured constants, so the **panel can
complete a whole cycle against nothing**:

```
fill    2.24 counts/s     12 fills, 5 cycles
heat    0.103 °C/s        24 -> 57 °C in 321 s
cool    tau 459 s         90 -> 36 °C over 13 min
reset   ~1.5 s after the intake motor is released
```

Overrides compose: `tempovr`, `flowspoof`, `status_ovr` and `lid` all apply to
the synthesised frame exactly as they would to a real one.

**Not persisted.** A reboot comes back in plain relay — returning from a crash
into "the machine is fake" would be a bad default.

### Why it exists

Most error codes are only evaluated while a cycle is running. `E7` is the proof:
set status bit 5 on an idle panel and nothing happens, set the same bit mid-cycle
and the panel displays `E7`. It was nearly documented as a dead bit.

So testing fault behaviour needs a cycle in progress, and a rig that can stage one
without water, heat or a 91-minute wait.

### Procedure

1. `POST /api/virtual?v=on&auto=on&temp=26&flow=0&st=0`
2. Start a cycle on the panel — nothing physical happens
3. Inject the fault at the phase you want to test
4. Read the display, then clear the injection **before** power-cycling, or the
   panel re-latches on the way back up

---

## Cycle runner

### `GET /api/cycle`

Stage table plus live state: `state` (0 idle, 1 running, 2 done, 3 aborted),
`stage`, `elapsed`, `why` (abort reason).

### `POST /api/cycle?run=start|stop|resume|defaults`
### `POST /api/cycle?mode=<0..5>`
### `POST /api/cycle?i=<n>&secs=<n>`

Start, stop, resume, restore the compiled defaults, switch program, or retime
stage `n`.

`state` is `0` idle, `1` running, `2` complete, `3` aborted, **`4` paused**. An
open lid or an empty tank **pause** rather than abort — a lid pause resumes on
its own once the lid shuts, a water pause waits for `run=resume`. Pausing
releases every load and keeps the stage and its elapsed time. Faults, over
temperature and a dead link still abort.

Six programs, from the manual (p.25–26). Each has its own stage list, its own
saved durations, and the manual's maximum water temperature as an abort ceiling
on top of the global one:

| n | Program | Max °C |
|---|---|---|
| 0 | Rapid Wash | 55 |
| 1 | Normal Wash (default) | 68 |
| 2 | Steam Sterilization | 96 |
| 3 | Drying | 96 |
| 4 | 72h Fresh Air Storage | 96 |
| 5 | Self-Cleaning | 70 |

### `POST /api/cycle?water=<°C>&dry=<°C>`

Temperature targets for the current program, persisted. `-1` or an omitted
argument leaves that one alone; `0` disables it.

**One sensor.** Byte 1 is the sump NTC and there is no air probe, so `water` is a
real setpoint (a `b2` heat stage ends when it is reached) while `dry` can only be
a ceiling on the same reading (a `b3`/`b4` stage aborts above it). Both are
clamped to the program's maximum.

`mode` is ignored while a cycle is running. Durations persist per program. **`secs=0` means run until the fill target is
reached** rather than for a fixed time — which is how the machine itself ends a
fill, and the only correct way to do it.

⚠️ This drives 110 V heaters and a water pump with the panel held idle and
nothing above it. The interlocks are in the runner because the machine has none:
no heater stage without a verified fill, and abort on fill stall, over
temperature, lid open, controller fault bit or a dead link. Abort clears every
override and releases every load.

Full state machine and stage table in [cycle.md](cycles.md).

### `GET /api/custom`
### `POST /api/custom?slot=<0|1>&name=<text>&stages=<spec>`

**Six** user-editable programs, appended after the six built-ins.

The canonical spec is **7 characters per stage**, concatenated: `CODEnnU` — a
4-letter code, two digits, and a unit (`S` seconds, `M` minutes, `H` hours, or
`P` for a fill percentage), comma separated. `[A-Za-z0-9,]` only, nothing to
URL-encode. Commas are optional on input and always present on output.

```
DRAN20S,FILL90P,WASH05M,FLSH70S,DRYR10M
```

Codes: `DRAN FILL PUMP WASH STEM AIRH BLOW DRYR FLSH WAIT` — see
[cycle.md](cycles.md#canonical-form--what-the-device-stores).

Three authoring forms are also accepted and produce identical bytes: hex
`LLTTSSSS`, `loads:target:seconds` comma separated, and readable stages such as
`drain 20s, fill 90, wash+heat 5m`. The device always returns the canonical
form.
`GET` returns every slot including the free ones, so an editor can offer them.

Delete with `POST /api/cycle?del=<slot>`. A free slot is not a program: it is
reported `"empty": true` in `/api/cycle` and `/api/app`, both pages hide it, and
`mode=` refuses to select it.

A rejected list returns **400** with the reason, so an editor can say why. The
rules and the evidence behind each are in [cycle.md](cycles.md#the-rules-and-why-each-exists)
— the short version is that the validator refuses to let you dry-fire the heater,
fill with no target, or run an untargeted flush with the drain shut, because the
machine checks none of those.

---

## Diagnostics

| Endpoint | Purpose |
|---|---|
| `POST /api/probe?v=on\|off` | Feed the controller a permanently idle panel frame. Buttons can be pressed with no possibility of starting a cycle |
| `POST /api/spoof` | Impersonate the panel toward the controller at ~200 ms |
| `POST /api/send?to=board\|panel&hex=...` | Raw frame injection |
| `POST /api/thin?panel=<n>&ctrl=<n>` | Forward only 1 frame in N toward each end — the TX-margin test |
| `POST /api/detect[?phase2=1]` | Pin-map scan. Phase 1 never drives a line; phase 2 latches `E5` on the panel |
| `POST /api/pinmap?rxb=&txb=&txp=&rxp=` | Set the pin map directly, persisted to NVS |
| `POST /api/sim?sw=2&v=on\|off` | Drive the lid switch input on the controller. `SW1` has no GPIO |
| `POST /api/flow?hz=<n>` | Flow-meter pulse simulator toward the controller. `hz=0` stops |
| `POST /api/baud?b=<n>` | Change the link baud, persisted |

## Resetting

| Endpoint | Clears |
|---|---|
| `POST /api/qclear` | Checksum counters |
| `POST /api/histclear` | Frame history |
| `POST /api/baseline` | Capture the current frames as the delta baseline |
| `POST /api/deltaclear` | Delta table |
| `POST /api/btnclear` | Last-button-code memory |
| `POST /api/flowlog?clear=1` | Flow event ring |
| `POST /api/clear` | The sniff ring |
| `POST /api/reboot` | Restarts the ESP32. A few seconds of link interruption |

## Firmware update

```
curl -f -F "firmware=@.pio/build/c3/firmware.bin" \
     "http://baby-washer.local/update?key=$OTA_PASSWORD"
```

Needs no reverse connection back to the uploading host, unlike espota. See
[ota.md](flash.md).

⚠️ **An OTA quiesces forwarding for 15–20 s.** Never mid-cycle. In virtual mode
it is worse — the panel receives nothing at all and will raise `E5`.

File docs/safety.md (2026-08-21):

# Safety

Read this before opening the machine.

This is a **120 V, 560 W appliance that heats water to near boiling**. The
low-voltage board you will be probing sits a few centimetres from live mains, and
the machine is designed to run unattended with a lid closed.

## Non-negotiables

**Unplug it before opening it.** Not "switched off" — unplugged. There is a
switching supply inside with charged bulk capacitors; give it a minute.

**Verify mains isolation before attaching an earthed scope ground.** Unplugged,
measure resistance from CN2 pin 3 (GND) to each mains pin on the cord. You want
**megohms**. If either reads low, stop — you have a non-isolated board, and an
earthed scope ground would be a short across the mains. Expect a small leakage
current through the primary-to-secondary Y-capacitor when you attach the clip;
that is normal, a dead short is not.

**Never put a scope ground clip on a supply positive.** Both channel grounds are
common and tied to earth.

**Set the bench up so you are not reaching over anything live** while the machine
is powered and open. You will be running cycles with the case off, and there will
be hot water.
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

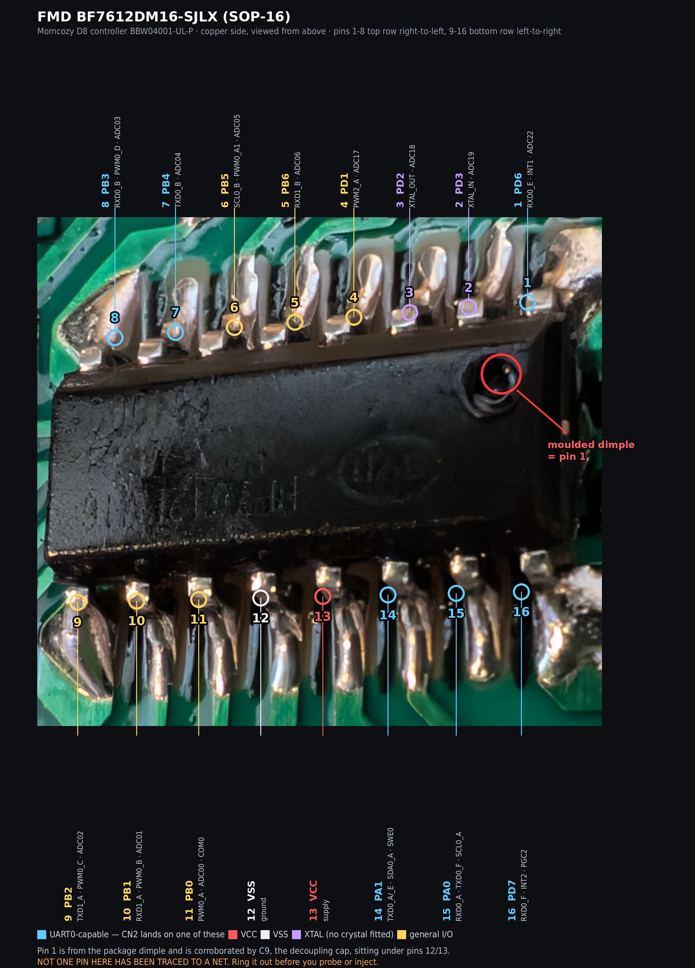
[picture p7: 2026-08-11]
docs/images/06-mcu-pinout-on-board.jpg

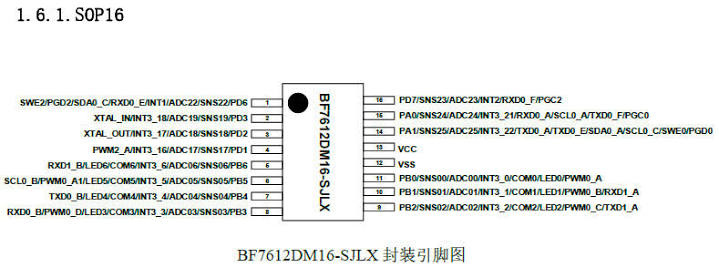
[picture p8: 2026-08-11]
docs/images/05-mcu-pinout.jpg

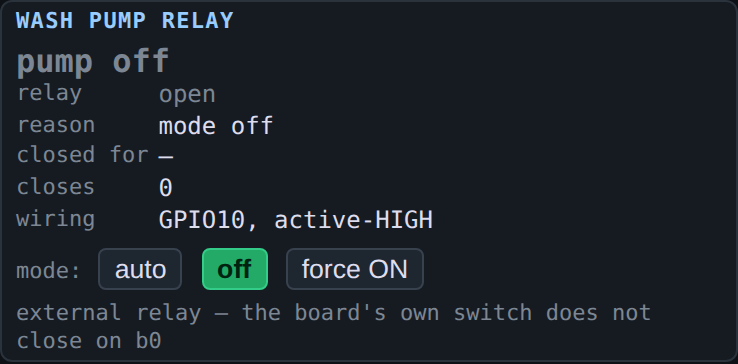
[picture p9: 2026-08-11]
docs/images/webui/wash-pump-relay.png

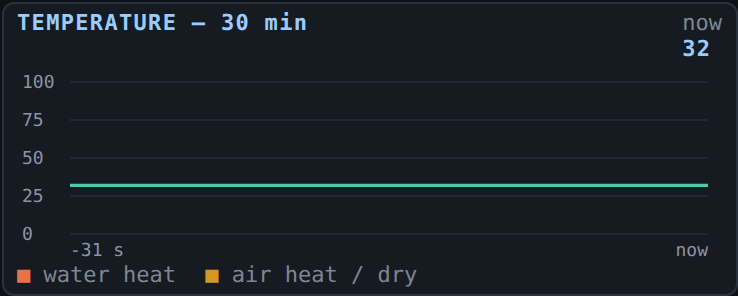
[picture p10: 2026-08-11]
docs/images/webui/temperature.png

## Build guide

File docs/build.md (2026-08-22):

# Build it

⚠️ Read [safety.md](safety.md) first. Unplug the machine before opening it.

⚠️ **This procedure was written on a Momcozy D8 (`BW05`).** The connector
location, pin order, logic level and load bits are that board's. On any other
machine, measure each of them yourself — steps 1–3 are exactly the measurements
that tell you whether it matches.

## Parts

| | |
|---|---|
| **Seeed XIAO ESP32-C3** | the brain. Any ESP32 with two hardware UARTs works; the pin advice below is C3-specific |
| **4-channel BSS138 level shifter** | the panel link is 5 V. Measure yours first — see below |
| 4-pin JST-XH pigtails ×2 | to splice into the panel connector, if you would rather not solder to the board |
| a few cm of wire, pin header | for the tap |
| *optional* relay module | only if a load needs driving directly — see [the wash-pump note](#if-a-load-will-not-switch) |

There is an optional carrier PCB in [`hardware/pcb/`](../hardware/pcb/) — a
31.5 × 26 mm board that holds the XIAO, the shifter and three connectors, with
Gerbers ready to order. Perfectly fine on stripboard instead.

## 1. Find the panel link

Look for a **4-pin connector** between the front panel and the controller board.
On the Momcozy D8 it is silkscreened `CN2` — the full board tour, including which
connector drives which load, is in [board.md](board.md).

<p align="center">
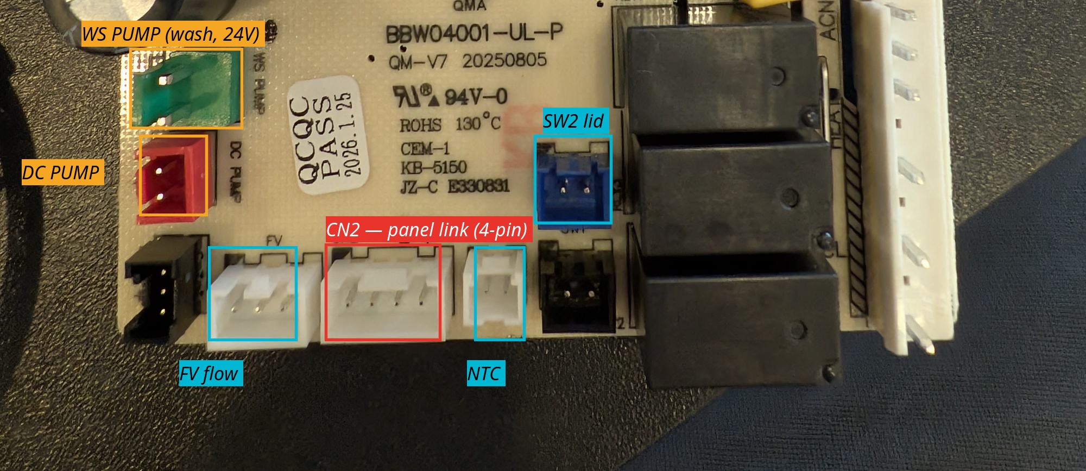
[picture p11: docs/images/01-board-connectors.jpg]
The D8 control board with its connectors labelled: CN2 panel link in red, flow meter and NTC and lid switch in cyan, wash and intake pumps in amber.
  
</p>

<p align="center">
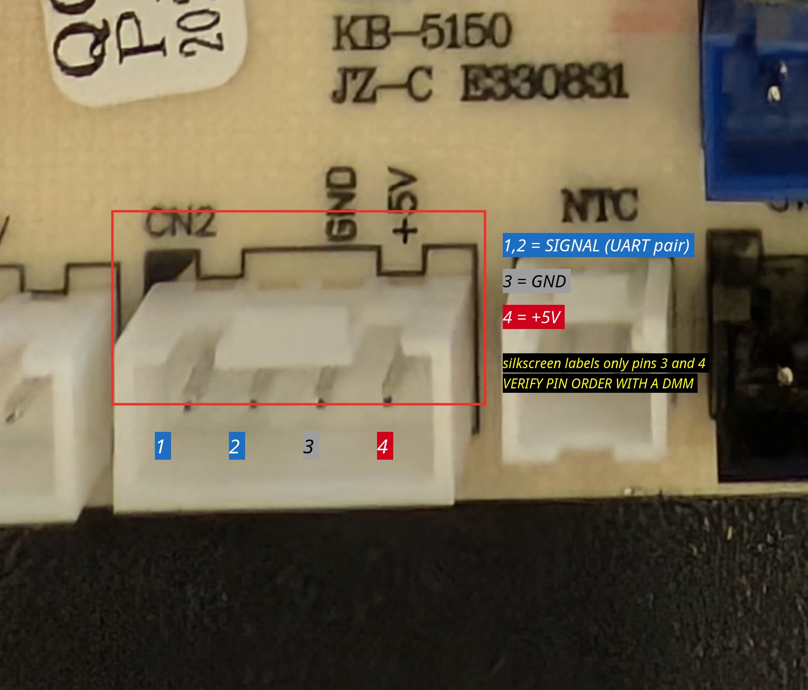
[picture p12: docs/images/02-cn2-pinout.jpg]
Close-up of the CN2 four-pin header: pins 1 and 2 are unlabelled signals, pin 3 is silkscreened GND, pin 4 is +5V.
  
</p>

Two pins carry signals, two carry power:

| Pin | Function |
|---|---|
| 1 | signal — controller → panel |
| 2 | signal — panel → controller |
| 3 | `GND` |
| 4 | `+5V` |

⚠️ **Confirm the order with a meter before trusting the silkscreen.** On this board
the rotated labels sit slightly right of the pins they name. Power the board, find
which pin sits at 5 V relative to chassis and which is continuous with ground.
Thirty seconds, and it is the one mistake that damages things.

## 2. Measure the logic level

**Do this before ordering anything.** CN2 supplies 5 V, and that does **not** mean
it signals at 5 V. Put a meter or a scope on a signal line at standby.

| Measured HIGH | What you need |
|---|---|
| ~5 V | **level shifter** (or a 10 kΩ / 20 kΩ divider on each ESP32 receive line) |
| ~3.3 V | **connect direct**, no shifter |

⚠️ Getting this backwards is the most expensive mistake available here: a 10k/20k
divider on an already-3.3 V line yields **~2.2 V**, below the C3's input threshold.
The symptom is a stream of framing errors that looks exactly like a wrong baud
rate, and you will spend the evening trying other baud rates.

The D8 measures **5.13 V**, so it needs the shifter.

## 3. Tap it — LISTEN first

**Do not cut anything yet.** Solder four short wires to the connector's pads on
the solder side and bring them to a header, or back-probe the housing. Leave the
panel plugged in.

Flash the firmware ([flash.md](flash.md)) and leave it in **LISTEN** mode, where
the UARTs are opened with no TX pin — the firmware physically cannot drive a line.
Then run:

```
POST /api/detect
```

It counts edges to find which two pins are driven, reads one frame off each, and
tells you which is the controller (`0xA2` header) and which is the panel (`0xAA`).
It never transmits.

**This is the step that makes the next one safe.** Connecting an ESP32 transmit
pin to something that is also an output is the way to damage a board.

## 4. Go inline

Two ways to get the ESP32 into the link. **Prefer the first — it cuts nothing.**

### A. Inline adapter (reversible)

`CN2` is a plug-in connector, so the module can sit **in** the cable:

```
controller  ──► [ J1  module  J2 ] ──►  panel
```

You need a 4-pin JST-XH **male** header toward the controller and a **socket**
for the panel's existing cable. The carrier board in
[`hardware/pcb/`](../hardware/pcb/) is exactly this — `J1` to the controller,
`J2` to the panel, with pins 3 and 4 passing straight through on the copper.

Unplug it later and the machine is stock. Nothing is cut, nothing is soldered to
the OEM board.

### B. Cut and splice

If you cannot source the connectors, cut **CN2 pins 1 and 2 only** and bring all
four stubs to the ESP32. Still reversible with a solder joint, but not as neatly.

⚠️ **Either way, leave pins 3 and 4 connected panel↔controller.** The panel is
powered through them; break all four and it goes dead.

<p align="center">
  As-built wiring: controller and front panel through all four channels of a BSS138 level converter to a XIAO ESP32-C3.
</p>

| ch | Stub | | Shifter | XIAO | UART |
|---|---|---|---|---|---|
| 1 | CONTROLLER pin 1 — output | → | `HV1` · `LV1` | `D1 / GPIO3` | `Serial0` **RX** |
| 2 | CONTROLLER pin 2 — input | ← | `HV2` · `LV2` | `D2 / GPIO4` | `Serial0` **TX** |
| 3 | PANEL pin 1 — input | ← | `HV3` · `LV3` | `D3 / GPIO5` | `Serial1` **TX** |
| 4 | PANEL pin 2 — output | → | `HV4` · `LV4` | `D4 / GPIO6` | `Serial1` **RX** |

**Power:** controller pin 4 (+5 V) = panel pin 4 = shifter `HV` = XIAO `5V`, one
net. XIAO `3V3` → shifter `LV`. Controller pin 3, panel pin 3, both shifter `GND`
pads and XIAO `GND` all common.

**The rule that decides every connection:** an **output** stub lands on an ESP32
**RX** pin; an **input** stub is **driven** by an ESP32 **TX** pin.

> If an ESP32 RX pin is wired to an *input* stub it sees no traffic at all and
> counts **zero bytes forever** — check `/api/status`. Nothing is ever transmitted
> on an input.

Two properties make the wiring hard to get wrong: **channel N carries pin DN**,
and **the HV side groups by device** — ch1/ch2 controller, ch3/ch4 panel.

⚠️ Wire to the shifter's **printed pad names**. Rotated so HV faces the machine,
its pads read `HV4 · HV3 · GND · HV · HV2 · HV1` down the board — not 1 to 4. The
photo inset in the diagram shows it.

## Pin choice, if you deviate

`D1`–`D4` are plain GPIOs. The others are not:

| Pin | Why not |
|---|---|
| **GPIO21 (D6)** | UART0 TX — the ROM bootloader transmits boot messages on it at every reset, injecting garbage into the panel link |
| GPIO9 (D9) | BOOT button **and** strapping — held low at reset means download mode |
| GPIO8 (D8) | strapping pin |
| GPIO2 (D0) | strapping pin |
| GPIO20 (D7) | UART0 RX — safe, it is an input |

<p align="center">
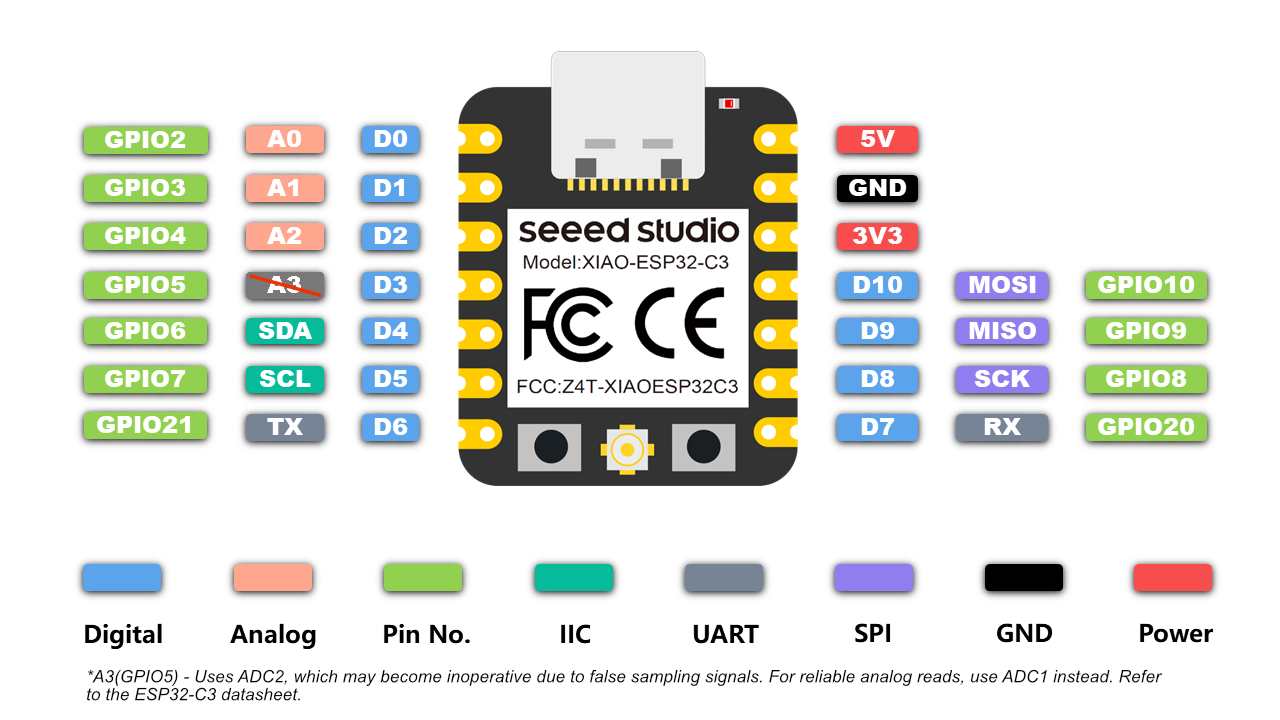
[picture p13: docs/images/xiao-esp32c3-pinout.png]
Seeed XIAO ESP32-C3 pinout: D0-D6 and their GPIO numbers on the left, 5V, GND, 3V3 and D10-D7 on the right.
  
</p>

<p align="center">
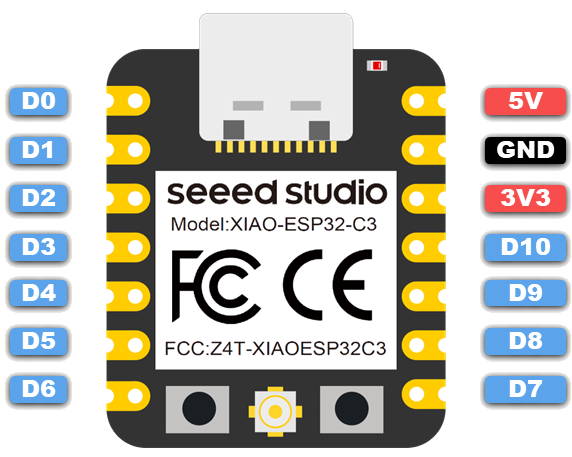
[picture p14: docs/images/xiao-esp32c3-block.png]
XIAO ESP32-C3 block diagram: the ESP32-C3 module, USB-C, battery charger and the 2x7 castellated pin rows.
  
</p>

<sub>XIAO ESP32-C3 pinout and block diagram © Seeed Studio.</sub>

The C3 routes UARTs through the GPIO matrix, so any free pin works and a UART's
two pins need not be adjacent. It has exactly **two** hardware UARTs — precisely
enough.

**Why BSS138 is fine on a UART:** open-drain, low side driven actively, high side
pulled up through ~10 kΩ, so rise time is RC-limited to ~0.5 µs — irrelevant
against a 104 µs bit at 9600 baud, and UART idles HIGH which is the right resting
state. Don't reuse this above a few hundred kbaud.

## Power

Take it from **CN2 pin 4**, shared with the shifter's `HV` reference.

⚠️ That rail was sized for a button panel drawing tens of milliamps, and an ESP32
peaks near 300 mA on WiFi transmit. It has proven adequate here, but if your panel
browns out, power the ESP32 separately and share only ground. Using pin 4 purely
as a level-shifter reference draws microamps and is always safe.

## If a load will not switch

On this machine the controller's own low-side switch for the **wash pump** does
not close when the panel commands it. The firmware can drive that load through an
**external relay module** on a spare GPIO instead, following the same bit the
machine would have used — so cycles behave normally.

Default pin is **GPIO10 (D10)**, active-high, runtime-settable via
`POST /api/wsrelay`.

⚠️ **Fit a pull-down resistor**: 10 kΩ from the relay pin to GND for an
active-high module (to 3V3 for active-low). The GPIO is high-impedance from reset
until the firmware starts, and in safe mode it is never configured at all — only a
passive resistor holds the load off in those windows. Prefer an opto-isolated
module with a separate `JD-VCC`.

## Confirm it

Do not assume it works because the machine looks normal — see
[troubleshooting.md](troubleshooting.md) for the four-path test, the link-quality
counters and the margin test.

## Hardening against interference

The machine's own loads have never corrupted the link — ~220k frames across
7.7 h of captured cycles, zero bad checksums — so these are prevention, sized
for the two paths that could actually bite: **supply sag** on the CN2 pin 4
rail, and the **relay + 24 V pump** the wash-pump workaround adds. The wiring
diagram's bottom panel shows where each part goes.

| Ref | Part | Where | Guards against |
|---|---|---|---|
| C1 | 470–1000 µF electrolytic | XIAO `5V`/`GND`, at the pins | brownout when a heavy load starts during a WiFi burst (300 mA peaks on a rail sized for a button panel) |
| C2 | 100 nF ceramic | beside C1 | HF that the electrolytic is too slow for |
| FB1 | ferrite bead, 600 Ω @ 100 MHz, low DCR | in the 5 V feed from CN2 | conducted noise from the machine's rail. A bead, **not a resistor** — 10 Ω at 300 mA would drop 3 V |
| D1 | SMBJ5.0A TVS | across 5 V/GND at cable entry | switch-off transients from the machine's relays and motors |
| R1 | 220 Ω | in series, D10 → relay `IN` | ringing and transients on the control line |
| R2 | 10 kΩ | D10 → GND (already specified) | pump energising while the GPIO is high-Z at reset |
| D2 | 1N4007 | **across the 24 V pump**, cathode to +24 V | coil kickback when the relay contact opens — the biggest transient source the mod adds |

- Relay module: **opto-isolated, JD-VCC jumper removed** — coil current from
  its own supply, kickback never reaches the ESP32 rail.
- AC loads (the drain pump, if ever switched externally): RC snubber
  100 Ω + 100 nF X2 across the contact — a diode cannot work on AC.
- Layout costs nothing and matters most: relay/pump wiring out of the CN2
  signal bundle, 5 V+GND twisted as a pair, one star ground at the shifter's
  GND pad, antenna clear of the mains loom.

**Verify after fitting:** `POST /api/qclear`, run a full cycle, then check
`bad_c`/`bad_p` stayed 0 and `boot_count` did not move. A brownout shows as
`boot_count` climbing with `reset_reason` 15.

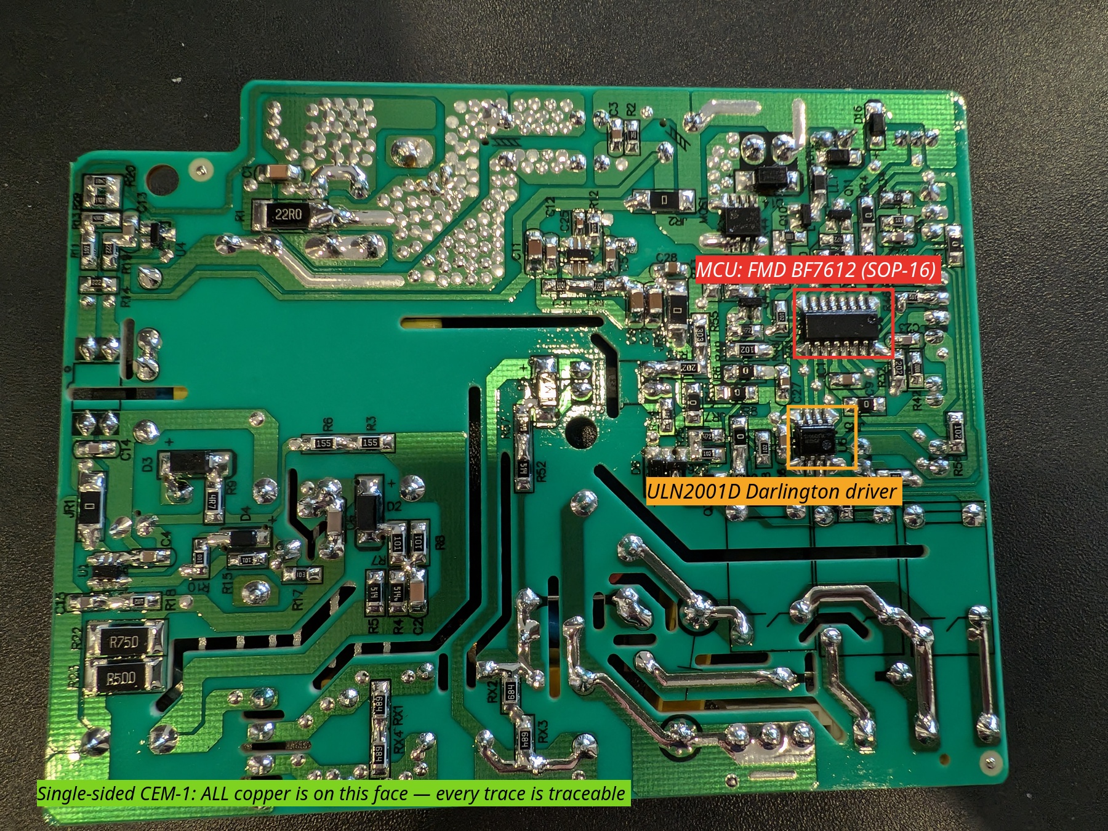
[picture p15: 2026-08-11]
docs/images/03-board-solder-side.jpg

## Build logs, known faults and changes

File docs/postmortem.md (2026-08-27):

# Postmortem: the E5 lockouts and everything mistaken for them

Aug 22–25, 2026, touch-panel D8 ("unit 2"). Every claim below is tied to a
recorded observation; where the evidence stops, the claim stops.

## What status bit 6 (panel: E5) actually is — PROVEN

The controller's **panel-frame-starvation latch**. Evidence:

1. On unit 1 the controller raises bit 6 when starved of panel frames
   (documented during the original build; there it clears again by itself).
2. Unit 2 latched it **seconds after power-on** twice (Aug 23, boot+60 s and
   boot+5 s) — precisely the window where the ESP32 is still booting and the
   inline link is dark. Closed by `earlyBridge()` (pads bridged in the first
   milliseconds of `setup()`, fw 1.15.0).
3. A 97-minute latch exactly spanned the one incident where forwarding
   provably wedged while the CPU stayed up (Aug 24 16:58, OTA interrupted the
   relay; 92 frames forwarded, then silence).
4. Frame data was never the cause: **zero bad checksums in either direction
   across the entire investigation** (~500k+ frames), byte counts in == out,
   and captured onsets show byte 3 as the only byte that changes.
5. The panel drops every load 0.2 s after seeing bit 6 and latches E5 on its
   display. On unit 2 the controller then ignores all load commands until
   **mains removal** — cut duration required is nondeterministic (field CSV:
   60 s failed 5/5, 120 s worked 3/5, 180 s worked 2/2).

## The Aug 23 lock storm (19 events) — mechanism proven, per-event trigger not

All 19 occurred under early firmware (1.2.0–1.13.x) whose relay ran without
today's instrumentation, so no per-event stall trace exists. What the record
supports: the starvation mechanism above, one measured 96.8 ms relay stall at
WiFi association, and locks recurring fastest when HTTP/recovery traffic was
heaviest. What ended them is a matter of record: from Aug 23 19:02 (bridge
forwarding from boot) — zero locks in 28 h; and Aug 25 (genuine CPU relay,
post-fix, profiled ≤9.6 ms worst stall under deliberate load) — zero locks
through manual load tests, a measured diagnostic, and three supervised cycles
including a full wash+steam+dry. The precise Aug 23 trigger was never
captured and is not claimed.

## The "CPU relay is cursed / wire mode is magic" myth — RETRACTED

`HardwareSerial::setPins()` is a silent no-op when pin numbers are unchanged,
so after the first wire-mode engagement, **every switch back to "CPU relay"
left the silicon bridge connected and the UART TX signals detached**
(1.14.0→1.15.0). Consequences, all reproduced and then fixed in 1.15.1:

- every mode-comparison datum in that window had bridge forwarding in both
  arms — the "wire = reliable / CPU = trouble" table was measuring one mode;
- every override (loads, lid forcing, cycle-runner stages, intake fills
  byte-identical to the panel's own `AA 20 AB 1C 3D`) was written into a
  detached UART — producing twelve hours of ghost theories (intake "gate"
  bytes, drain choreography, atomic transitions, lid switches, tank seats);
- the proof of fix: the first intake command after 1.15.1 pulled water
  (flow 0→40) with the exact bytes "refused" all morning.

Post-fix reality: **genuine CPU relay is the operating mode and runs
lock-free** (Aug 25, hours of operation, full cycles). Wire mode remains a
diagnostic, engaged only on explicit request.

## Errors that were never bit 6

- **E1 / "no water" (Aug 24 morning)** — genuine: a panel-driven fill moved
  64 counts and stalled; water was not reaching the pump; reseating the tank
  fixed it. Honest machine behavior.
- **"Intake and drain stuck on"** — the controller's own autonomous flush
  routine; it self-terminated (~10 min) and left no fault. Not welded relays
  (a weld cannot release itself).
- **WiFi/page lag/OTA failures** — a link that degrades with uptime and
  resets to full speed on reboot (1.29 MB OTA: 14.5 s on a fresh boot; the
  same transfer died 8× on an aged link). Mechanism unproven; unrelated to
  the machine (wire/CPU forwarding both immune). The 11 dBm TX cap was ruled
  out as the lock cause (locks predate it) and removed regardless.

## Self-recovery limits — measured, not assumed

The ESP32 is powered from CN2 pin 4, i.e. by the smart plug it can switch.
Three mechanisms for surviving its own mains cut were tested on the HS103:
`count_down` is cancelled by any manual relay write; a one-off `schedule`
rule survives the relay change but never fires; the `count_down` table holds
exactly one rule ("table is full"). **Self-power-cycle is impossible with
this plug.** The self-contained design therefore is: detect the latch
(`locked_ms`), protect (StuckLoad → one-way mains cut), persist cycle
progress, and after a *human* power cycle, auto-resume behind strict gates
(link settled, controller clear, panel idle, 20 s stable uptime, one-shot).

## The NVS shared-handle trap (found while making CPU relay the boot default)

Several setters call `begin()/end()` on the shared `Preferences` handle;
afterwards, reads through that handle return defaults and writes fail
silently. The boot path then did `read wire pref (default true) →
wireSet(true) → persist true`, actively overwriting a stored `false` on
every boot. Proven by readback: `stored:false` before boot, `stored:true`
after. Fixed by local handles at every persist/read site (1.16.1–1.16.3);
boot default verified across power cycles.

## Final architecture (1.16.3)

ESP32 100 % self-contained: CPU relay forwarding + full override capability,
safety guards (fill-stall, heat ceiling, stuck-load mains cut), lock
detection, NVS cycle persistence with gated auto-resume. Home Assistant
polls read-only REST for display. No PC or HA daemon exists in the running
or recovery path. Removed as dead or externally-coupled: the HA watchdog,
telemetry logger, reachability watcher, lockout webhook (`hook.cpp`),
FlushCap, DrainExtend, the WiFi TX cap.

## Addendum (Aug 26): two more, both caught by the app's new flush button

- **A 0xFF flush is controller-LATCHED**: it ignores a plain load release and
  ends only when water stops arriving — the machine's own programs end it the
  same way. Stopping one therefore means intake OFF, drain HELD (~20 s) until
  the controller notices dry and terminates, then release. Releasing
  everything at once leaves the intake running until a power cycle. (This is
  also the behavior the removed FlushCap guarded — its mechanism was right
  even if the feature was dead weight.)
- **The idle-stream parse alias**: lose one byte on `AA 00 00 00 AA` traffic
  and the previous frame's checksum plays the header — fake frames that
  XOR-validate and self-sustain, wedging position-keyed rewrites forever
  (observed as `b1fwd=0xAA`). Detection needs the byte-1 invariant (panel
  byte 1 never carries bits 6/7); recovery needs a wire-gap-phased re-lock,
  because header-hunting from inside the alias re-locks the same phase.
  Fixed in cn2core::FramePos with host tests (fw 1.16.5).

## Addendum (Aug 26 night): the TX-to-controller channel died — hardware

Evening-long E5 recurrence, finally isolated to a one-direction hardware
failure between our TX pad and the controller's RX pin (level-shifter
channel 2 / HV2 wiring, per the build map). Evidence chain, all remote:
the TX pad demonstrably drives (edge counts mirror the forwarded panel
frames), 13k+ bytes queued with zero errors our side — while the controller
executes nothing through any state: intake moves no water, 60 s of
commanded wash+heat moves the NTC 0.0 °C, and it latches bit 6 seconds
after every boot exactly as a panel-starved controller should. The
controller->us direction stayed perfect throughout, which is why every
software probe said "healthy". Firmware was exonerated by rollback (the
field-proven 1.15.1 behaved identically) and by the masked-boot race.
Repair: meter HV2 (should idle ~5 V), swap the BSS138 board. The E5Model
host tests cover every firmware-caused starvation; this failure class --
dead copper past the pad -- is detectable at runtime only as "controller
stops obeying while its frames keep arriving", now documented as the
signature to check FIRST before another twelve-hour software hunt.

## Addendum (Aug 26, late): boot-sequence profile — the definitive answer

Frame-level capture of a failing boot, diffed against archived healthy
traffic (captures/boot-frames-e5-20260826.txt):

    t=105 ms   panel:      AA 00 00 00 AA            first poll, on time
    t=109 ms   controller: A2 00 00 00 04 00 03 ...  byte3 CLEAR at birth
    t=711 ms   controller: byte5 initializes to 0x0A  (healthy logs: 0x09)
    t=5113 ms  panel:      AA 00 00 00 AA            25th perfect poll
    t=5125 ms  controller: byte3 0x00 -> 0x40        LATCHES, mid-dialogue

The dialogue is exonerated at the frame level: 200 ms cadence unbroken,
every checksum valid, the polls before and after the latch byte-identical.
The controller boots CLEAR and latches on its own ~5 s check. The named
culprit is in byte 5: healthy 0x09 (0b1001), failing 0x0A (0b1010) --
bit 0 OFF and bit 1 ON, the signature of ONE changeover switch (NC/NO
pair) that physically flipped inside the machine during the flood window
and has stayed flipped through every power cycle since: a float/leak
switch held up by water (or stuck). When it drops, byte 5 reads 0x09
again and boots pass the 5-second check. Nothing on the CN2 wire can
change it.

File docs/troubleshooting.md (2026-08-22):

# Troubleshooting the CN2 interception

Everything here is testable from the web UI on an idle machine — no oscilloscope,
no water, no cycle. It works because **both OEM MCUs watchdog the link**: if either
stops receiving valid frames it raises **E5** (the panel on its display, the
controller in `byte3 b6`), so the machine is its own test rig and a dead path
announces itself within seconds.

## 1. The four paths

| # | Path | Direction | Confirmed by |
|---|---|---|---|
| ch1 | controller pin 1 → HV1·LV1 → D1/GPIO3 | into ESP | `ctrl→ESP` counter climbing, **0 bad** |
| ch2 | D2/GPIO4 → LV2·HV2 → controller pin 2 | out of ESP | controller `byte3 b6` (E5) stays clear |
| ch3 | D3/GPIO5 → LV3·HV3 → panel pin 1 | out of ESP | **no E5 on the panel display** |
| ch4 | panel pin 2 → HV4·LV4 → D4/GPIO6 | into ESP | `panel→ESP` counter climbing, **0 bad** |

Channels come from [wiring.md](build.md#4-go-inline); if you
wired it differently, `POST /api/detect` tells you what you actually have.

The two RX paths prove themselves — every frame ends in an XOR, so a corrupted byte
is caught and counted. **The two TX paths are blind**: the ESP32 cannot see its own
output, and they are proven only by the far end's watchdog staying quiet.

### ⚠️ E5 does not, by itself, isolate a TX path

If **ch1** is broken the ESP32 has nothing to forward, so the panel raises E5 *even
with a perfect ch3*. Read the RX counter first:

| `ctrl→ESP` counter | Panel display | Verdict |
|---|---|---|
| climbing, 0 bad | no E5 | **ch3 good** |
| climbing, 0 bad | **E5** | **ch3 is the fault** |
| stalled | E5 | ch1 broken — says nothing about ch3 |

Mirror the logic for ch2, reading E5 off controller `byte3 b6` instead.

## 2. Autodetect

```
POST /api/detect             phase 1 only — passive
POST /api/detect?phase2=1    also resolve the transmit stubs
GET  /api/detect             results
```

**Phase 1 never drives a line.** It leans on two facts: only the two OEM *outputs*
have edges (the inputs sit idle-high because nothing drives them yet), so counting
edges for 700 ms splits four pins into two receive and two transmit stubs; and the
headers name the device — `0xA2` is the controller, `0xAA` the panel, with the XOR
proving it is not noise.

```
GPIO3    108 edges  <- driven     rx controller  (0xA2)
GPIO4      0        silent        tx stub
GPIO5      0        silent        tx stub
GPIO6     66 edges  <- driven     rx panel       (0xAA)
```

The edge counts are a sanity check: 108/66 = 1.64 against a frame-length ratio of
8/5 = 1.6. Real traffic, not pickup. Phase 1 cannot tell **which** transmit stub
goes where — both are silent by definition.

**Phase 2** closes the loop through the far end: forward on a guess, then read the
**controller's E5 bit** back over the receive path phase 1 just confirmed. Only two
permutations, so one trial resolves it, and the result is saved to NVS. The
controller's bit is used specifically because it **clears itself** when the link
recovers; the panel's latches.

> ⚠️ **The panel will be showing `E5` when phase 2 finishes and needs a power
> cycle.** That is the unavoidable cost of interrupting the link to test a
> permutation.

When you already know the answer, skip the trialling — persisted to NVS, applied
immediately, no reflash:

```
POST /api/pinmap?rxb=5&txb=6&txp=3&rxp=4
```

Worth running after rewiring, when porting to a machine whose pin directions are
unknown (phase 1 removes the one mistake that can damage a board), or to rule the
pin map out in 2 seconds.

## 3. Test sequence

Run in order; stop at the first failure.

**Test 0 — power up, wait 5 s, look at the panel.** No E5 means ch3 is alive.

**Test 1 — idle 10 minutes, `LINK QUALITY` → `reset` first.** Roughly 3000 frames
each way. Zero bad on both rows means ch1 and ch4 are clean. **Any** non-zero bad
count is the finding: a partly-damaged BSS138 or a cold joint does not fail
outright, it drops the occasional bit, and only the counter catches that.

**Test 2 — ch3, actively.** Toggle the lid override and watch the icon follow. This
proves the bytes are *parsed*, not merely keeping the watchdog fed.

**Test 3 — ch2, actively.** Anything the controller visibly reacts to. Forcing
panel bytes 2–3 is *not* such a test — it does not start a cycle.

## 4. TX margin test — measuring a blind path

Tests 0 and 2 give one bit of information. A channel that is merely *weak* passes
both and fails later, so `/api/thin` makes the blind paths quantitative:

```
POST /api/thin?panel=4&ctrl=1     forward only 1 frame in 4 toward the panel
POST /api/thin?panel=1&ctrl=1     back to full rate
```

Starve one far end and find the N at which it raises E5. **Baseline it on wiring
you trust first** — the absolute number is meaningless alone; a channel that
silently drops frames fails at a lower N than it did before.

## Error codes — BW05 manual, p.29

**There is no E2** — the manual skips it. `E1` is *Water Inlet Fault*, not "no
water"; water shortage is a separate indicator alert.

| Code | Manual text | Evidence on CN2 | How to raise it |
|---|---|---|---|
| `E0` | Voltage Anomaly | ✅ **byte 3 bit 4** | set bit 4 |
| `E1` | Water Inlet Fault | ⚠️ no bit | starve byte 2 during a fill — untested, needs a cycle |
| `E3` | Sensor Open Circuit | ✅ **byte 3 bit 2** | set bit 2 |
| `E4` | Sensor Short Circuit | ✅ **byte 3 bit 3** | set bit 3 |
| `E5` | Communication Failure | ✅ **byte 3 bit 6** | set bit 6, or cut the link |
| `E6` | Heating Plate Malfunction | ⚠️ no bit | pin byte 1 while the heater runs — untested, needs a cycle |
| `E7` | Fan Failure | ✅ **byte 3 bit 5** | set bit 5 **while a cycle runs** — nothing at idle |

`E0`, `E3`, `E4`, `E5`, `E7` are confirmed: each bit was injected and the panel
displayed the matching code. Three things to know:

- **They latch.** One frame is enough and the code holds until a power cycle.
- **The lowest set bit wins.** `0x0C` (bits 2+3) shows `E3` — independent flags,
  not a code field.
- **Forcing byte 1 does not raise `E3`/`E4`.** Tested at `0x00` and `0xFF`.

`E1` and `E6` have no bit, and **`E1` is not a stalled-flow verdict** — zero flow
for 330 s with intake commanded produced nothing. Neither end has a fill timeout.

Two conditions are **indicator alerts, not codes**, and clear themselves:

| Alert | Manual text | On CN2 |
|---|---|---|
| Water Shortage | add water, press Start/Pause, auto-resumes | inferred from byte 2 |
| Lid Open | closes automatically when the lid is shut | byte 3 bits 1 and 7 |

To raise one deliberately see [api.md](api.md#lying-to-the-panel), and
[api.md](api.md#virtual-controller--a-panel-test-rig) for the rig that stages a
cycle without water — required, because `E7` and probably `E1`/`E6` are only
evaluated mid-cycle.

## 5. What a healthy link looks like

```
ctrl ->ESP   297 good, 0 bad
panel->ESP   295 good, 0 bad
byte3 = 0x02     lid reed set (lid off), E5 clear
```

Both sides broadcast every ~200/201 ms, so ten minutes is roughly 3000 frames each way.
A counter that climbs but falls well short means you are losing frames, not the
link — which is what the bad-checksum column and the TX-margin test catch.

Two protocol facts are worth repeating here because they cause misdiagnosis: **the
two sides are free-running, not request/response**, so any "reply latency" is
drifting phase between independent clocks; and **`E5` is symmetric**, so on its own
it never tells you which end lost the link.

## 6. Logging a cycle

**Nothing is stored on the ESP32.** The firmware keeps a 4096-event byte ring —
about 63 seconds at ~65 bytes/s — plus a 24-entry run-length history per direction.
A wash cycle runs 20–40 minutes, so the ring wraps roughly 38 times and a reboot
loses all of it. Capture from the host **before** you start:

```bash
python3 tools/cycle_log.py --out logs/mycycle --hz 5
```

It polls `/api/status`, writes a line whenever the frames change plus a 30 s
heartbeat, and flushes on every write, so a crash costs at most the current line.
Two files: `.jsonl` for analysis, `.log` for reading live. Network drops are
written into the log rather than waited out silently — a gap is evidence.

## 7. If the ESP32 disappears from the network

It is powered from CN2 pin 4, so **if the D8 is unplugged the ESP32 is off** —
check that before assuming a bad flash. If it is powered and still absent, scan the
subnet rather than trusting mDNS; `.local` resolution has proven unreliable here.
If an OTA reports success but the device comes back on the *old* version, the
upload did not apply — re-flash and confirm with `/api/version`.

## 8. Testing the flush cap

The end-of-cycle flush is capped in firmware ([`POST /api/flushcap`](api.md)).
Two ways to prove it works, in the order worth doing them.

### Dry — no water, machine inert

```bash
python3 tools/flushcap_test.py baby-washer.local
```

**SPOOF** feeds the controller a permanently idle panel frame, so nothing the
overrides say reaches it and no load can be energised. The masks are still
applied to the real panel stream on the way past, and that rewritten value is
what the cap watches — so the whole decision path runs while the machine sits
still. The script refuses to command anything until it has confirmed spoof is
engaged, and restores the link in a `finally`.

It checks four things: a **targeted** fill is never capped however long it runs,
an untargeted `0xFF` flush trips the cap on time, the forwarded byte 1 loses
`INTAKE` and keeps `DRAIN`, and releasing the flush re-arms it.

On the `/dev` page the same thing is visible live: while the cap holds, the
`→ctrl` column of **DRIVE LOADS** shows `b5` as `0` with a red `*`, and the
**FLUSH CAP** line reads `CAPPED`.

### Wet — a real cycle

The dry test cannot tell you the one thing only the machine knows: **whether the
controller accepts a mid-flush intake release and moves on.** For that:

1. `POST /api/flushcap?ms=20000`
2. Start **Self-Clean** and let it run to the cool-down flush (last stage before
   drying, ~60–115 s of drain and intake together).
3. Watch `/api/status`: `flush_on` goes true, `flush_ms` climbs, and at 20 s
   `flush_cap` goes true. The serial log prints `[flush] CAP at 20000 ms`.
4. The sump temperature should stop falling and start rising within a few
   seconds — that is the machine seeing the water stop, which is exactly what
   ends the stage normally.
5. Confirm the cycle advances to drying rather than sitting there.
6. Put the cap back: `POST /api/flushcap?ms=180000`.

⚠️ Capture it: `python3 tools/cycle_log.py --out logs/flushcap --hz 5`. Nothing
is stored on the ESP32, so an uncaptured run tells you nothing afterwards.

If the cycle **stalls** at step 5, the controller wants something else to end
that stage and the cap is the wrong lever — set `ms=0`, open an issue with the
log, and bound the water supply in hardware instead.

## 9. `E5` on the panel right after power-on

`E5` is *Communication Failure*, and it **latches at the panel** — once raised it
stays on the display until the machine is power-cycled, however healthy the link
becomes afterwards. So the first question is never "why is E5 showing" but
"is anything still causing it".

Check `/api/status`:

| Field | What it means |
|---|---|
| `st_real` | the controller's **own** status byte. `0x40` = it is asserting the comms fault right now. `0x00` = it is happy and the panel display is just stale |
| `st_set` | non-zero means **you** are injecting the bit — clear it with `/api/status_ovr?clr=0&set=0` |
| `bad_c` / `bad_p` | anything above zero is a corrupted byte on the wire |
| `tx_to_board` vs `panel_bytes` | must be equal — every byte received is forwarded |
| `tx_to_panel` vs `board_bytes` | likewise, the other direction |

`/api/hist` gives the same in order. Its `first` column is an **age in seconds,
not a timestamp**, so read it descending to get chronological order — that is
what tells you whether the fault was there from the first frame or arrived later.

⚠️ **This module is powered from CN2 pin 4**, so it boots at the same instant as
the panel and the controller, and until its UARTs open both TX pins float.
Firmware before **1.1.0** opened them *after* a 1.5 s `while (!Serial)` wait and
a blocking WiFi association — a measured **4.0 s** with the panel link dead at
every power-on, and up to 20 s with the access point down. Newer D8 controllers
raise a comms fault over that. 1.1.0 opens the link first; the same measurement
now reads **0.0 s**. Check with `/api/version`.

Confirmed on the machine that showed the fault: after 1.1.0 and a power cycle,
209 s with the controller's status byte never leaving `0x00`, 1046 controller and
1048 panel frames, **zero bad checksums**, boot dead window **0.00 s**. It had
previously raised the bit ~52 s in and held it.

Measure it yourself — the byte counters are exact:

```bash
# dead window = uptime - (bytes / steady rate).  Controller 40 B/s, panel 25 B/s.
curl -s http://baby-washer.local/api/status |
  python3 -c 'import sys,json;d=json.load(sys.stdin);print(d["uptime_s"]-d["board_bytes"]/40)'
```

⚠️ **Safe mode leaves the UARTs shut**, so the panel and controller cannot reach
each other at all — the machine will show `E5` and refuse to run. It is not a
broken appliance; power-cycle to clear the boot-loop guard.

### Forwarding stalls

`worst_gap_us` is the longest the relay task went between forwarding passes —
1 ms in steady state. `worst_gap_at` says **when**, in millis from boot, which is
the half that matters: WiFi association starves the task for ~96 ms and there is
no stopping that, but ~96 ms is eleven byte times at 9600 baud and wide enough to
split a frame at whichever end is mid-transmission. Landing in the window the
panel and controller use to find each other is a different thing from landing
afterwards.

So the firmware forwards on a quiet link until ten good frames have arrived each
way (~2 s) and only then brings up the radio. Measured after the change: worst
gap 96.2 ms at **t=3.69 s**, clear of the startup window. Both counters reset
with `POST /api/qclear`.

⚠️ **A weak radio used to take the panel link down with it.** `net::loop()`
restarts the board after 60 s without WiFi, and every restart drops forwarding
for a whole boot — long enough for a panel to latch `E5`, which then needs an
appliance power cycle to clear, to recover a radio a restart usually cannot fix.
From 1.2.0 the restart only fires when the CN2 link has gone idle too; while
frames are flowing it re-kicks the supplicant indefinitely and logs that it is
holding off. Check `rssi`: −59 dBm is comfortable, −78 is not.

### If the panel is stricter than the controller

The two ends do not tolerate the same silence. Starved deliberately
(`/api/thin`), this controller raises its comms bit after **~8 s** without a
panel frame. A touch panel can fault on far less — a measured **96 ms**
forwarding stall during WiFi association (a flash write disables the
instruction cache; no task priority helps) split a frame mid-transmission and
was enough for one panel to latch `E5` a few seconds after every power-on,
while the controller never noticed anything.

From 1.3.0 forwarding is **frame-atomic**: rewritten bytes are coalesced and
the UART is handed the whole frame in one write, so the 128-byte TX FIFO clocks
it out with no further CPU involvement. A stall can delay a frame — a one-off
296 ms beat instead of 200 — but never split one on the wire. Unknown-header
bytes still pass through immediately, so the relay stays transparent to noise.

⚠️ An OTA update still interrupts forwarding for 15–20 s, which is beyond both
ends' tolerance — expect a latched `E5` after any flash, and power-cycle the
machine to clear it. That is the update, not a fault.

### The false-`E5` filter

On the newer board (controller byte 6 = `0x03`), status bit 6 is **not only a
comms fault**. Observed on a byte-exact link, frame counters never missing a
beat:

- raised **2 s after every power-on** while the sump is still warm — before
  WiFi even associates, and with the controller's very first frame clean
- raised again **the instant a dry stage ends**, in the same 200 ms window the
  panel goes idle, then held while the machine runs its 72 h storage
  autonomously (the panel commands nothing all night)

The panel has one meaning for that bit, latches it, and needs a power cycle to
clear — so a healthy machine sat showing `E5` permanently.

`POST /api/e5filter?mode=off|auto|force` (default **auto**, NVS-persisted).
AUTO does not hide the bit, it **disproves** it: we are the link being
complained about, so the claim is refused only while all four hold —

| | |
|---|---|
| transparent relay | full rate, no probe / spoof / virtual — each of those is *us* breaking the link, and a fault raised then is earned |
| controller frames fresh | < 1 s |
| panel frames fresh | < 1 s |
| zero bad checksums | corruption is real evidence *for* the fault |

Fail any one and bit 6 passes through untouched. `st_set` is applied after the
filter, so deliberately injecting `E5` for testing still works.

Status carries `e5f_mode`, `e5f_on`, `e5f_n`, `e5f_why`; the dev page's
CONTROLLER → PANEL card shows the live verdict.

⚠️ It cannot clear a latch already on the display — **power-cycle once after
enabling.** And if you ever see `E5` return *with the filter on*, that is
meaningful: it means the filter refused to mask, so read `e5f_why`.

If the link is clean and `st_real` is `0x00` but the panel still shows `E5`,
power-cycle the machine. If `E5` comes straight back, take the module out of the
loop — panel plugged directly into the controller — and power on. Clean without
it means the problem is in our path; `E5` anyway means it is the machine.

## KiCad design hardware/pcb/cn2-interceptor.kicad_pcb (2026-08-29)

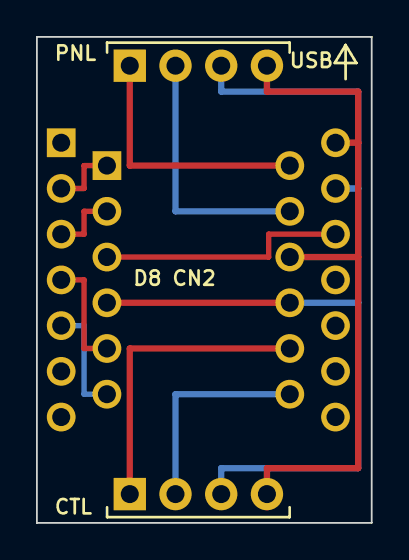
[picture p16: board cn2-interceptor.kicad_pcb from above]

Board: 2 copper layers, 18.6 x 27.0 mm, 4 parts (0 on the bottom side), 11 nets.

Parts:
J1: JST-XH 4P (CONTROLLER); JST_XH_4
J2: JST-XH 4P (PANEL); JST_XH_4
U1: XIAO ESP32-C3; XIAO_ESP32C3_2X7
U2: 4CH BSS138 LEVEL SHIFTER; LEVELSHIFT_2X6

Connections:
+3V3: U1.3V3, U2.LV
+5V: J1.4, J2.4, U1.5V, U2.HV
CH1_HV: J2.1, U2.HV1
CH1_LV: U1.D1, U2.LV1
CH2_HV: J2.2, U2.HV2
CH2_LV: U1.D2, U2.LV2
CH3_HV: J1.1, U2.HV3
CH3_LV: U1.D3, U2.LV3
CH4_HV: J1.2, U2.HV4
CH4_LV: U1.D4, U2.LV4
GND: J1.3, J2.3, U1.GND, U2.GND_H, U2.GND_L

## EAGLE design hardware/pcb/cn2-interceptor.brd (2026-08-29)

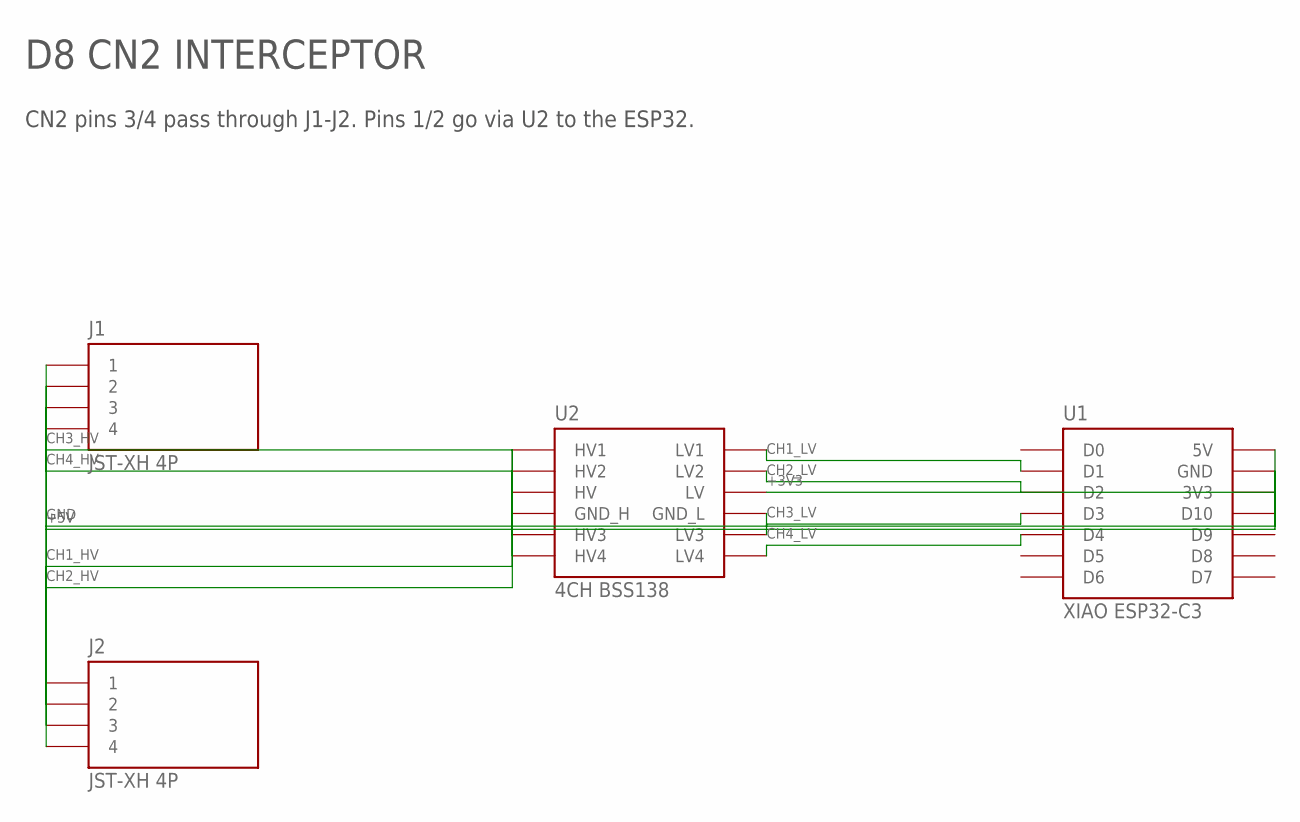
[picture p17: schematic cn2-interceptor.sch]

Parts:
J1, J2: JST-XH 4P; JST_XH_4
U1: XIAO ESP32-C3; XIAO_2X7
U2: 4CH BSS138; LS_2X6

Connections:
+3V3: U1.3V3, U2.LV
+5V: J1.4, J2.4, U1.5V, U2.HV
CH1_HV: J2.1, U2.HV1
CH1_LV: U1.D1, U2.LV1
CH2_HV: J2.2, U2.HV2
CH2_LV: U1.D2, U2.LV2
CH3_HV: J1.1, U2.HV3
CH3_LV: U1.D3, U2.LV3
CH4_HV: J1.2, U2.HV4
CH4_LV: U1.D4, U2.LV4
GND: J1.3, J2.3, U1.GND, U2.GND_H, U2.GND_L

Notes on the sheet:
D8 CN2 INTERCEPTOR
CN2 pins 3/4 pass through J1-J2. Pins 1/2 go via U2 to the ESP32.

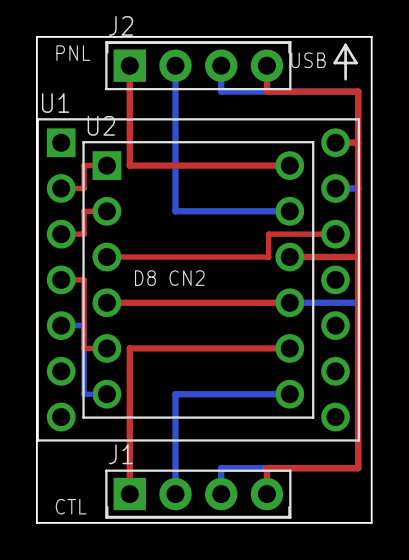
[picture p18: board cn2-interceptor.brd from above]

Board: 2 copper layers, 18.6 x 27.0 mm, 4 parts (0 on the bottom side), 11 nets.

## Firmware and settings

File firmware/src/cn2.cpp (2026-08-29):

#include "cn2.h"

#include <esp_task_wdt.h>

#include "kasa.h"
#include <esp_system.h>
#include <rom/rtc.h>
extern "C" uint64_t esp_rtc_get_time_us(void);
#include <ctype.h>
#include <cn2core.h>

#include <Preferences.h>
#include "esp_rom_gpio.h"
#include "soc/gpio_sig_map.h"
#include "soc/gpio_struct.h"
#include "hal/gpio_ll.h"
#include <esp_timer.h>

#include "config.h"

namespace cn2 {

struct Ev {
  uint32_t t_us;
  uint8_t  side;
  uint8_t  b;
};

static Ev       s_ring[SNIFF_RING];
static uint32_t s_head = 0;                 // monotonic write cursor
static uint32_t s_count[2] = {0, 0};
static uint32_t s_last_ms[2] = {0, 0};
static uint32_t s_overflow = 0;
static uint32_t s_tx[2] = {0, 0};
static esp_timer_handle_t s_flow_timer = nullptr;
static uint32_t s_flow_hz = 0;
static volatile uint32_t s_flow_pulses = 0;
static volatile bool s_flow_level = true;
static bool s_sim[2] = {false, false};
static uint8_t  s_done[2][24], s_donen[2] = {0, 0};
static volatile uint32_t s_seq[2] = {0, 0};   // seqlock guarding s_done/s_donen

// Copy the last complete frame from one side without tearing. Returns its
// length, or 0 if none has arrived yet or a writer kept winning the race.
// Everything reported over HTTP goes through here, so the decoded fields and the
// raw hex in the same response are always from the same frame.
static uint8_t frameSnapshot(uint8_t side, uint8_t *out) {
  if (side > 1) return 0;
  for (uint8_t tries = 0; tries < 8; tries++) {
    uint32_t a = s_seq[side];
    if (a & 1u) continue;                     // writer mid-copy
    uint8_t n = s_donen[side];
    if (n > 24) n = 24;
    memcpy(out, s_done[side], n);
    if (s_seq[side] == a) return n;           // nothing moved underneath us
  }
  return 0;
}
static uint8_t  s_lid_mode = 0;   // 0 = pass real, 1 = force LID ON, 2 = force LID OFF
static bool     s_lid_real = false;  // bit1 as RECEIVED from the controller
static bool     s_lid_fwd  = false;  // bit1 as SENT on to the panel
static uint8_t  s_st_clr = 0x00;     // byte3 bits force-CLEARED toward the panel
static uint8_t  s_st_set = 0x00;     // byte3 bits force-SET toward the panel
static uint8_t  s_st_real = 0, s_st_fwd = 0;
static bool     s_flow_spoof = false;          // hold the panel's flow count at 0
static uint8_t  s_flow_real = 0, s_flow_fwd = 0;
// VIRTUAL CONTROLLER. The ESP32 synthesises the controller->panel frame itself
// and the real controller's frames are dropped. The panel sees a healthy machine
// reporting whatever we choose; the real controller is fed the idle panel frame,
// so it stays in sync and E5-free but is never asked to do anything.
//
// This is the mirror of PROBE mode, which does the same trick in the other
// direction. Together they let the panel be exercised with the machine
// electrically inert.
static bool     s_virt = false;
static uint32_t s_virt_last = 0, s_virt_n = 0;
static uint8_t  s_virt_temp = 30, s_virt_flow = 0, s_virt_st = 0x00,
                s_virt_b5 = 0x0B;   // 0x0B is byte 5's most common value, 56%
// AUTO: run a simple model of the machine so the PANEL can complete a real
// cycle against it. Without this the panel commands a fill, the flow count never
// moves, and it stalls or faults -- which makes it impossible to reach the
// states where most error codes are evaluated.
//
// Every constant here is measured from captures/, not invented:
//   fill    2.24 counts/s      12 fills, 5 cycles
//   heat    0.103 C/s          24 -> 57 C in 321 s, wash cycle
//   cool    tau 459 s          90 -> 36 C over 13 min, storage hold
//   reset   ~1.5 s after the intake motor is released
static bool     s_virt_auto = true;
static float    s_virt_tempf = 30.0f, s_virt_flowf = 0.0f;
static uint32_t s_virt_sim_ms = 0, s_virt_intake_off = 0;

static int16_t  s_temp_ovr = -1;               // -1 = pass; else force byte 1
static uint8_t  s_temp_real = 0, s_temp_fwd = 0;
// Injected button press: OR'd into byte 1 of the panel->board frame for a while.
// Rewrite of byte 1 on its way panel->controller:  out = (b & ~clr) | set
//
// Byte 1 bit 5 (0x20) is the INTAKE MOTOR, not a RUN or pause flag. Setting it
// runs the pump; there is no gating of any kind. Two earlier readings of this
// bit — "pause", then "RUN" — were both wrong, and both came from short bench
// captures. Five full cycles settled it: the bit is on exactly while water is
// being drawn, and byte 2 counts pulses throughout.
static uint8_t  s_p1_clr = 0, s_p1_set = 0;
// Byte 3 is the FILL TARGET for the next fill; byte 2 always accompanies it and
// has never been seen to vary independently. Substituting them changes how much
// water a fill draws. It does NOT start a cycle — that was tested and ruled out,
// and there is no RUN flag for the controller to assert.
static int16_t  s_p2_ovr = -1, s_p3_ovr = -1;
static uint8_t  s_press_mask = 0;
static uint32_t s_press_until = 0;
static uint8_t  s_pb_i = 0, s_pb_x = 0;
static cn2core::FrameTx s_pb_tx;    // checksum decision, panel->controller
static cn2core::FramePos s_pb_pos;
static uint32_t s_pb_prev = 0;
static uint8_t  s_panel_b1 = 0, s_panel_b2 = 0, s_panel_b3 = 0;
// Byte 1 as FORWARDED, i.e. what the controller is actually told to energise.
// Differs from s_panel_b1 whenever an override or the cycle runner is driving:
// the real panel sends 0x00 and the command exists only in the rewritten stream.
static uint8_t  s_panel_b1_fwd = 0;
// Byte 1 as the overrides WANT it, before the flush cap subtracts the intake
// bit. The cap has to latch off this value, not off s_panel_b1_fwd: the moment
// it strips b5 the condition it triggered on would read false, un-latch, and
// the pair would oscillate at the frame rate.
static uint8_t  s_panel_b1_want = 0;
// Byte 3 as forwarded, so the cap sees the target the CONTROLLER is acting on
// rather than the one the panel asked for.
static uint8_t  s_panel_b3_fwd = 0;
// ---- untargeted-flush cap (see FLUSH_CAP_MS_DEFAULT in config.h) ----------
static cn2core::FillStall s_fstall;   // panel-run fill guard; see cn2core
static cn2core::HeatCeiling s_heat;   // panel-run heater backstop
static cn2core::StuckLoad   s_stuck;  // mains cut-out; see cn2core::StuckLoad
static uint16_t s_stuck_off_s = 30;
static uint8_t  s_e5f_mode = E5F_AUTO;   // false-E5 filter; see e5FilterActive()
static uint32_t s_wifi_delay = 0;   // radio hold at boot; see setWifiDelayMs()
// PROBE mode: the controller is fed a permanently idle panel frame while the
// real panel's bytes are still captured. Buttons can then be pressed freely to
// learn their codes without any of them reaching the controller.
static bool     s_probe = false;
static uint8_t  s_b1_last = 0;      // most recent NON-ZERO byte 1 seen
static uint32_t s_b1_at = 0;
static uint32_t s_b1_n = 0;

// ---- delta detector -------------------------------------------------------
// Snapshot an "idle" frame per direction, then record every DISTINCT frame that
// differs from it. Answers "did anything at all change while I did X?" without
// staring at a scrolling log.
// Per-direction run-length history: an identical repeat only bumps the count and
// the last-seen time; anything different appends a row that then persists. The
// whole session's distinct frames stay on screen instead of scrolling away.
struct Hist { uint8_t n, b[12]; uint32_t first_ms, last_ms, count; };
#define HIST_MAX 24
// 0 = RX from controller   1 = RX from panel
// 2 = TX to panel           3 = TX to controller   (i.e. after any rewrite)
static Hist    s_hist[4][HIST_MAX];
static uint8_t s_histn[4] = {0, 0, 0, 0};

// Assemble the frames we actually SEND, so the UI can show received vs
// transmitted side by side and any override is visible rather than inferred.
static void histAdd(uint8_t side, const uint8_t *f, uint8_t n);
static cn2core::Assembler s_asm_out[2];

static inline void collectOut(uint8_t dir, uint8_t b) {
  uint8_t n = s_asm_out[dir].feed(b);
  if (n) histAdd(2 + dir, s_asm_out[dir].buf, n);
}

static void histAdd(uint8_t side, const uint8_t *f, uint8_t n) {
  if (n > 12) n = 12;
  uint8_t &c = s_histn[side];
  if (c) {
    Hist &last = s_hist[side][c - 1];
    if (last.n == n && !memcmp(last.b, f, n)) {     // same as last -> just tick
      last.count++; last.last_ms = millis(); return;
    }
  }
  if (c >= HIST_MAX) {                              // full: drop the oldest
    memmove(&s_hist[side][0], &s_hist[side][1], sizeof(Hist) * (HIST_MAX - 1));
    c = HIST_MAX - 1;
  }
  Hist &h = s_hist[side][c++];
  h.n = n; memcpy(h.b, f, n);
  h.first_ms = h.last_ms = millis(); h.count = 1;
}

struct Delta { uint8_t side, n, b[12]; uint32_t first_ms, count; };
static Delta   s_dl[10];
static uint8_t s_dln = 0;
static uint8_t s_base[2][12], s_basen[2] = {0, 0};

static void deltaCheck(uint8_t side, const uint8_t *f, uint8_t n) {
  if (!s_basen[side]) return;                       // no baseline yet
  if (n == s_basen[side] && !memcmp(f, s_base[side], n)) return;   // matches idle
  for (uint8_t i = 0; i < s_dln; i++)
    if (s_dl[i].side == side && s_dl[i].n == n && !memcmp(s_dl[i].b, f, n)) {
      s_dl[i].count++; return;
    }
  if (s_dln >= 10) return;                          // table full, keep the first 10
  Delta &d = s_dl[s_dln++];
  d.side = side; d.n = (n > 12) ? 12 : n;
  memcpy(d.b, f, d.n); d.first_ms = millis(); d.count = 1;
}
static uint8_t  s_bp_i = 0;             // index within the current board frame
// The checksum decision for the controller->panel direction. cn2core owns it
// so it is exercised on the host; see cn2core::FrameTx.
static cn2core::FrameTx s_bp_tx;

// PURE mode and the edit counters answer one question: are we a wire?
//
// "Byte-perfect" is worth nothing as a claim about the code, because the claim
// goes stale the next time a rewrite is added -- that is exactly how the stale
// checksum bug happened. So it is measured instead, at the single point where a
// byte leaves us: compare what we are about to emit against what we received.
// That catches every rewrite path, including ones not yet written.
//
// s_pure forces the emitted byte back to the received byte at that same point,
// so it disables all rewriting in both directions regardless of which feature
// asked for it, now or later.
static bool     s_pure   = false;
static uint32_t s_lock_ms = 0;      // millis when bit 6 was first seen held
static uint32_t s_edit_c = 0;   // bytes we changed, controller->panel
static uint32_t s_edit_p = 0;   // bytes we changed, panel->controller
static cn2core::FramePos s_bp_pos;   // byte index, counted not timed
static uint8_t  s_bp_x = 0;             // XOR of bytes we have actually SENT
static uint32_t s_bp_prev = 0;   // bytes actually written out: [0]=to board, [1]=to panel

static uint32_t s_baud    = DEFAULT_BAUD;
static bool     s_open    = false;
static bool     s_capture = true;

static Preferences s_prefs;

// The panel's idle "nothing pressed" frame, captured on the wire.
static const uint8_t PANEL_IDLE[5] = {0xAA, 0x00, 0x00, 0x00, 0xAA};
static uint8_t  s_spoof_fr[16] = {0xAA, 0x00, 0x00, 0x00, 0xAA};
static uint8_t  s_spoof_len = 5;
static bool     s_spoof = false;
static uint32_t s_spoof_ms = 200;      // matches the observed ~200 ms poll
static uint32_t s_spoof_last = 0;
static uint32_t s_spoof_n = 0;
static TaskHandle_t s_task = nullptr;
static void relayTask(void *);   // defined below; started from begin()

static uint8_t  s_wsr_mode  = WSR_AUTO;
static bool     s_wsr_on    = false;
static bool     s_wsr_low   = (WS_RELAY_ACTIVE_LOW != 0);
static int8_t   s_wsr_pin   = PIN_WS_RELAY;
static bool     s_wsr_lock  = false;      // hit the cap; waits for the command to drop
static uint32_t s_wsr_since = 0;
static uint32_t s_wsr_n     = 0;
static const char *s_wsr_why = "boot";

static void wsrIdlePin(int8_t pin);
static void wsrService();
static void wsrDrive(bool on, const char *why);
static void pump();
static void wsrPanelFrame();
static void flushFrame();
static void closePorts();   // ordered teardown; see the definition
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
void loop() {
  selfHealTick();
  resumeTick();
  // Forwarding runs in relayTask(); the only work here is flushing the cycle
  // persistence record, so the flash writes happen in this task, never there.
  const uint8_t want = s_cyc_save;
  if (want) {
    const uint32_t t0 = micros();
    s_cyc_save = 0;
    // Local handle for the same reason as wireSet(): the shared s_prefs can
    // have been closed by any setter's begin()/end() pair, and a cycle whose
    // progress silently fails to persist is a cycle that cannot survive a
    // recovery power cycle.
    Preferences p; p.begin("d8link", false);
    if (want == 1) {
      p.putUChar("cyc_m", s_cyc_save_m);
      p.putUChar("cyc_i", s_cyc_save_i);
      p.putBool("cyc_w", s_cyc_save_w);
      p.putBool("cyc_on", true);
    } else if (p.getBool("cyc_on", false)) {
      p.putBool("cyc_on", false);
    }
    p.end();
    profNote(1, micros() - t0);
  }
}

void setLidMode(uint8_t m) {
  s_lid_mode = (m > 2) ? 0 : m;
  static const char *N[] = {"PASS (real)", "FORCE LID ON", "FORCE LID OFF"};
  Serial.printf("[lid  ] forward mode: %s\n", N[s_lid_mode]);
}
uint8_t lidMode()  { return s_lid_mode; }
bool    lidReal()  { return s_lid_real; }   // as received
bool    lidFwd()   { return s_lid_fwd; }    // as forwarded

void setStatusMask(uint8_t clr, uint8_t set) {
  s_st_clr = clr; s_st_set = set;
  Serial.printf("[stat ] byte3 override: clear 0x%02X, set 0x%02X\n", clr, set);
}
uint8_t statusClr()  { return s_st_clr; }
uint8_t statusSet()  { return s_st_set; }

// ===========================================================================
// PIN AUTODETECT
//
// Phase 1 is passive and cannot damage anything: the ESP32 never drives a line.
// It leans on two facts. First, the two OEM *outputs* are the only CN2 pins with
// edges on them — the OEM inputs sit idle-high because nothing is driving them
// yet. Second, the frame headers name the device: 0xA2 can only be the
// controller, 0xAA can only be the panel, and the XOR proves it is not noise.
//
// Phase 2 identifies the two transmit stubs, which the ESP32 cannot observe
// directly. It forwards on a guess and reads the controller's own E5 bit
// (status byte 3, bit 6) back over the receive path phase 1 just confirmed.
// There are only two permutations, so one trial resolves it.
//
// Cost: the panel latches E5 while this runs and needs a power cycle afterwards.
// The controller's bit clears itself, which is why it is the one used as the
// feedback signal.
// ===========================================================================

static Detect s_det;
static volatile uint32_t s_edge_n[4];
static TaskHandle_t s_det_task = nullptr;

static void IRAM_ATTR edgeIsr(void *arg) { s_edge_n[(uintptr_t)arg]++; }

// Listen on one pin for `ms` and report which frame header validates there.
static uint8_t sniffHeader(HardwareSerial &u, int8_t rx, uint32_t ms) {
  u.begin(s_baud, SERIAL_8N1, rx, -1);
  u.setRxFIFOFull(1);
  u.setRxTimeout(1);
  uint8_t buf[8], n = 0, expect = 0;
  uint32_t a2 = 0, aa = 0, t0 = millis();
  while ((uint32_t)(millis() - t0) < ms) {
    while (u.available()) {
      uint8_t b = (uint8_t)u.read();
      if (n == 0) {
        if (b == 0xA2)      expect = 8;
        else if (b == 0xAA) expect = 5;
        else continue;
      }
      buf[n++] = b;
      if (n >= expect) {
        uint8_t x = 0;
        for (uint8_t i = 0; i + 1 < n; i++) x ^= buf[i];
        if (x == buf[n - 1]) { if (buf[0] == 0xA2) a2++; else aa++; }
        n = 0;
      }
    }
    vTaskDelay(1);
  }
  u.end();
  if (a2 && a2 >= aa) return 0xA2;
  if (aa) return 0xAA;
  return 0;
}

// Forward on the current pin map for `ms`, then report the controller's E5 bit.
// trialClearsE5() below passes when the controller's E5 bit is CLEAR, so it can
// only tell two transmit permutations apart if the bit is SET when the trial
// starts. On a controller that was never faulted, the first permutation passes
// on its first poll -- including when it is the wrong one, which phase 2 then
// writes to NVS. On a board sealed inside an appliance that trades a
// half-working link for a dead one, so provoke the fault first and refuse to
// guess if it never comes.
static bool provokeE5(uint32_t ms) {
  s_pin_txb = -1; s_pin_txp = -1;      // LISTEN: the ports open with no TX pin
  openPorts();
  s_capture = true;
  const uint32_t t0 = millis();
  while ((uint32_t)(millis() - t0) < ms) {
    vTaskDelay(pdMS_TO_TICKS(50));
    if (s_st_real & 0x40) return true;
  }
  return false;
}

static bool trialClearsE5(uint32_t ms) {
  openPorts();
  s_capture = true;
  // s_st_real holds whatever the LAST decoded controller frame said -- including
  // 0 if none has ever been decoded. Sampling it before a fresh frame lands made
  // !(0 & 0x40) true immediately, so the first permutation always looked like a
  // success and the second was never tried. Wait for real frames first.
  const uint32_t start_ok = s_ok[0];
  uint32_t t0 = millis();
  while ((uint32_t)(millis() - t0) < 1200 && (s_ok[0] - start_ok) < 3)
    vTaskDelay(pdMS_TO_TICKS(20));
  if ((s_ok[0] - start_ok) < 3) return false;   // not even hearing the controller

  t0 = millis();
  while ((uint32_t)(millis() - t0) < ms) {
    vTaskDelay(pdMS_TO_TICKS(50));
    if (!(s_st_real & 0x40)) return true;       // E5 cleared -> it hears us
  }
  return false;
}

static void detectTask(void *arg) {
  const bool do_phase2 = (bool)(uintptr_t)arg;
  const int8_t cand[4] = { (int8_t)PIN_RX_BOARD, (int8_t)PIN_TX_BOARD,
                           (int8_t)PIN_TX_PANEL, (int8_t)PIN_RX_PANEL };
  const int8_t save[4] = { s_pin_rxb, s_pin_txb, s_pin_txp, s_pin_rxp };

  s_det = Detect();
  for (int i = 0; i < 4; i++) s_det.cand[i] = cand[i];
  s_det.running = true;
  s_det.phase   = 1;

  // ---- phase 1a: which pins are being driven? ----------------------------
  closePorts();
  for (int i = 0; i < 4; i++) {
    s_edge_n[i] = 0;
    pinMode(cand[i], INPUT);
    attachInterruptArg(digitalPinToInterrupt(cand[i]), edgeIsr,
                       (void *)(uintptr_t)i, CHANGE);
  }
  vTaskDelay(pdMS_TO_TICKS(700));            // >= 3 frame periods on both sides
  for (int i = 0; i < 4; i++) detachInterrupt(digitalPinToInterrupt(cand[i]));

  int act[4], nact = 0;
  for (int i = 0; i < 4; i++) {
    s_det.edge[i] = s_edge_n[i];
    if (s_edge_n[i] > 20) { if (nact < 4) act[nact] = i; nact++; }
  }
  if (nact != 2) {
    snprintf(s_det.note, sizeof(s_det.note),
             nact < 2 ? "Found %d driven pin(s), expected 2. Machine powered? CN2 stubs landed?"
                      : "Found %d driven pins, expected 2. Two ESP32 TX pins may be fighting an OEM output.",
             nact);
    goto restore;
  }

  // ---- phase 1b: which device is on each driven pin? ---------------------
  {
    uint8_t h0 = sniffHeader(uBoard, cand[act[0]], 600);
    uint8_t h1 = sniffHeader(uPanel, cand[act[1]], 600);
    if (h0 == 0xA2 && h1 == 0xAA) { s_det.rx_ctrl = cand[act[0]]; s_det.rx_panel = cand[act[1]]; }
    else if (h0 == 0xAA && h1 == 0xA2) { s_det.rx_ctrl = cand[act[1]]; s_det.rx_panel = cand[act[0]]; }
    else {
      snprintf(s_det.note, sizeof(s_det.note),
               "Both pins are driven but the headers did not resolve (%02X / %02X). "
               "Wrong baud, or a stub on the wrong pin.", h0, h1);
      goto restore;
    }
  }

  // the two silent candidates are the transmit stubs
  {
    int8_t tx[2]; int nt = 0;
    for (int i = 0; i < 4; i++)
      if (cand[i] != s_det.rx_ctrl && cand[i] != s_det.rx_panel && nt < 2) tx[nt++] = cand[i];
    s_det.tx_a = tx[0];
    s_det.tx_b = tx[1];
  }

  if (!do_phase2) {
    snprintf(s_det.note, sizeof(s_det.note),
             "Phase 1 only. RX pins identified; GPIO%d and GPIO%d are the transmit "
             "stubs but which is which is untested.", s_det.tx_a, s_det.tx_b);
    goto restore;
  }

  // ---- phase 2: which transmit stub goes to the controller? --------------
  s_det.phase = 2;
  s_pin_rxb = s_det.rx_ctrl;
  s_pin_rxp = s_det.rx_panel;

  // Starve the controller until it says so. Without this the trial below has
  // nothing to discriminate on -- see provokeE5().
  if (!provokeE5(PHASE2_PROVOKE_MS)) {
    snprintf(s_det.note, sizeof(s_det.note),
             "The controller did not raise E5 after %lu s with nothing transmitted "
             "to it, so there is no signal to resolve the transmit pins against. "
             "Phase 2 cannot run here -- set them by hand with POST /api/pinmap.",
             (unsigned long)(PHASE2_PROVOKE_MS / 1000));
    goto restore;
  }
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

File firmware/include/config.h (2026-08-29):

#pragma once
// Momcozy D8 CN2 sniffer — build-time configuration.
// Secrets (WiFi + OTA password) live in secrets.h, which is gitignored.

#include "secrets.h"

#define FW_NAME     "d8-cn2sniffer"
#define FW_VERSION    "1.18.5"


// ---- Network identity ------------------------------------------------------
// mDNS name, so nothing has to track the DHCP lease. Both the browser UI and
// the OTA uploader follow the board instead of an address that moves.
#define OTA_HOSTNAME              "d8-sniffer"
#define OTA_PORT                  3232

#define WIFI_CONNECT_TIMEOUT_MS   20000UL   // stop *blocking* after this...
#define WIFI_RETRY_MS             10000UL   // ...then re-kick the supplicant
#define WIFI_REBOOT_AFTER_MS      60000UL   // ...and finally reboot, but only
                                            // if the CN2 link is idle too
// How quiet the panel link must be before a WiFi restart is allowed to take it
// down with it. Both ends broadcast every ~200 ms, so 3 s is fifteen missed
// frames -- by then there is no link left to protect.
#define WIFI_REBOOT_LINK_IDLE_MS  3000UL

// ---- Robustness ------------------------------------------------------------
// The task watchdog is deliberately slack. It exists to catch a wedged loop(),
// not to police latency — and an OTA flash write blocks loop() for seconds at a
// time. (net.cpp feeds it from the OTA progress callback so that is safe.)
#define WDT_TIMEOUT_MS            30000UL

// Boot-loop guard. Three resets without ever reaching a healthy uptime and we
// come up with the payload disabled and nothing running but WiFi + OTA.
#define SAFE_MODE_AFTER_BOOTS     3
#define HEALTHY_UPTIME_MS         30000UL   // uptime WITH WiFi that clears it

// ---- CN2 tap ---------------------------------------------------------------
// XIAO ESP32-C3 pin choice, see ../D8_REPAIR_SSOT.md §7b:
//   D1..D4 are plain GPIOs — no strapping function, no ROM boot chatter.
//   Avoided: GPIO2/8/9 (strapping; GPIO9 is also the BOOT button) and GPIO21,
//   which is UART0 TX by default and which the ROM bootloader transmits boot
//   messages on at every reset — wiring that to a line the main board listens
//   on would inject garbage into the panel link on every reset.
//
// UART0 faces the main board, UART1 faces the front panel.
//
// AS-WIRED on the bench (2026-08-06), through a 4-ch BSS138 level converter:
//
//   controller pin 1  (board TX, OUTPUT) -> HV1 -> LV1 -> D1 / GPIO3   RX
//   controller pin 2  (board RX, INPUT)  -> HV3 -> LV3 -> D2 / GPIO4   TX
//   panel      pin 1  (panel RX, INPUT)  -> HV2 -> LV2 -> D3 / GPIO5   TX
//   panel      pin 2  (panel TX, OUTPUT) -> HV4 -> LV4 -> D4 / GPIO6   RX
//
// The invariant that makes this safe: every ESP32 RX pin sits on a stub that is
// DRIVEN by the other end, and every ESP32 TX pin sits on a stub that is an
// INPUT at the other end. Two outputs on one wire is the only way to do damage.
// Straight-through: converter channel N carries pin DN, so the board and the
// converter line up one-to-one and there is nothing to mis-read. Any assignment
// works electrically -- the C3's GPIO matrix routes a UART's RX and TX to any
// pins -- so this is chosen for legibility, not necessity.
//
// These are only the DEFAULTS. /api/detect writes a discovered map to NVS, and
// a saved map wins over anything here.
// AS-BUILT map for THIS module (rewired 2026-08-25; differs from
// docs/build.md, which describes the original layout). Field-proven twice:
// frames decode only on rxb=5/rxp=4 (zero frames on the old defaults after
// an NVS wipe), and an intake command emitted on txb=6 moved real water.
// Keep these matching the copper -- a default/physical mismatch means an
// NVS wipe silently kills the link.
#define PIN_RX_BOARD    5     // <- controller output
#define PIN_TX_BOARD    6     // -> controller input
#define PIN_TX_PANEL    3     // -> panel input
#define PIN_RX_PANEL    4     // <- panel output

// ---- flow meter, J3 on the carrier board -----------------------------------
// The board splices the FV signal line the same way CN2 is spliced: cut it,
// meter side to J3.1, controller side to J3.2. The ESP32 then sees every real
// pulse and decides what the controller is told.
//
// Both signals must come off the SAME side of the XIAO to be routable on a
// 2-layer board, and of the three GPIOs left free only GPIO10 (D10) and GPIO20
// (D7) are on the right-hand column -- GPIO7 (D5) is on the left. That is what
// moved FLOW_SIM off GPIO7.
//
// FLOW_SIM is OPEN-DRAIN on purpose: the hall sensor is open-collector with a
// 10k pull-up, so we only ever pull low and let that pull-up make the high
// level. Two open-drain outputs wire-OR, so the real sensor can stay connected.
#define PIN_FLOW_IN     10    // D10 <- J3.1, pulses from the real meter
#define PIN_FLOW_SIM    20    // D7  -> J3.2, what the controller sees
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

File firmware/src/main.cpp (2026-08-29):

// Momcozy D8 — CN2 panel-link sniffer / relay on a Seeed XIAO ESP32-C3.
//
// Sits on the 4-pin CN2 header between the D8 main board (FMD BF7612 8051) and
// its front panel, logs every byte in both directions, and — in RELAY mode —
// forwards them so the machine keeps working while we decode the protocol.
//
// See ../D8_REPAIR_SSOT.md §7b for the CN2 pinout and the wiring rationale.
//
// Design priority, in order:
//   1. WiFi and OTA must ALWAYS come back, whatever the payload does.
//   2. Never drive a CN2 line until the directions are known (/api/detect).
//   3. Then capture everything.

#include <Arduino.h>
#include <WiFi.h>
#include <esp_ota_ops.h>
#include <esp_task_wdt.h>
#include <Preferences.h>

#include "app.h"
#include "config.h"
#include "cn2.h"
#include "kasa.h"
#include "net.h"
#include "web.h"

// ---------------------------------------------------------------------------
// Boot-loop guard.
//
// The failure a "robust OTA" setup actually has to survive is flashing something
// that crashes before WiFi comes up. Without a guard, that board is bricked until
// it goes back on the USB cable — and this one will be inside an appliance.
//
// RTC_NOINIT memory survives a reset, including a panic or watchdog reset, but
// not a power cycle. That is exactly the right scope: three resets without ever
// reaching a healthy uptime and we come up in SAFE MODE with the payload
// disabled and nothing running but WiFi, mDNS and both OTA paths. Pull the power
// and it starts clean.
// ---------------------------------------------------------------------------
static const uint32_t BOOT_MAGIC = 0xD8C2A11EUL;

RTC_NOINIT_ATTR static uint32_t rtc_magic;
RTC_NOINIT_ATTR static uint32_t rtc_boots;

static bool     g_safe_mode = false;
static uint32_t g_boot_count = 0;
static uint32_t g_boot_ms = 0;
static bool     g_marked_ok = false;

namespace app {
bool     safeMode()        { return g_safe_mode; }
uint32_t bootCount()       { return g_boot_count; }
bool     imageMarkedGood() { return g_marked_ok; }
}  // namespace app


// ---------------------------------------------------------------------------
// USB serial console + radio-off mode.
//
// When the module is on a USB cable there is a channel that costs the machine
// nothing: no association, no DHCP, no ~300 mA transmit bursts on the CN2 5 V
// net. That matters here because the radio is the last unexonerated load in
// the E5 investigation -- WiFi is precisely what we want to be able to switch
// OFF while keeping full telemetry.
//
// "nowifi" in NVS skips net/web/kasa entirely; everything is then driven from
// this console. Read and written through a LOCAL Preferences handle -- the
// long-lived one belongs to cn2 and begin()/end() on it breaks that owner.
// ---------------------------------------------------------------------------
static bool     g_nowifi  = false;
static bool     g_mon     = false;   // periodic one-line telemetry
static uint32_t g_mon_ms  = 0;
static char     g_cbuf[48];
static uint8_t  g_clen    = 0;

static bool nowifiStored() {
  Preferences p;
  if (!p.begin("d8link", true)) return false;
  const bool v = p.getBool("nowifi", false);
  p.end();
  return v;
}

static void nowifiStore(bool v) {
  Preferences p;
  if (!p.begin("d8link", false)) return;
  p.putBool("nowifi", v);
  p.end();
}

static void monLine() {
  const uint8_t st = cn2::statusReal();
  Serial.printf("[mon  ] t=%6lus st=0x%02X%s%s temp=%u ok_c=%lu ok_p=%lu "
                "bad=%lu/%lu bb=%lu pb=%lu age_c=%ldms\n",
                (unsigned long)(millis() / 1000), st,
                (st & 0x40) ? " LATCH" : "",
                (st & 0x82) ? " LID"   : "",
                (unsigned)cn2::tempReal(),
                (unsigned long)cn2::frameOk(0), (unsigned long)cn2::frameOk(1),
                (unsigned long)cn2::frameBad(0), (unsigned long)cn2::frameBad(1),
                (unsigned long)cn2::byteCount(cn2::FROM_BOARD),
                (unsigned long)cn2::byteCount(cn2::FROM_PANEL),
                (long)cn2::lastByteAgeMs(cn2::FROM_BOARD));
  if (cn2::wire()) Serial.print(F("[mode ] WIRE — E5 mask inert (pad bridge)\n"));
  Serial.printf("[mask ] mode=%u on=%d masked=%lu leaks=%lu why=%s\n",
                (unsigned)cn2::e5FilterMode(), (int)cn2::e5FilterMasking(),
                (unsigned long)cn2::e5FilterFrames(),
                (unsigned long)cn2::e5FilterLeaks(), cn2::e5FilterWhy());
  // The whole controller frame, because byte 5 is the earliest divergence
  // known: the 2026-08-26 latch capture shows it settle to 0x0A at t=710 ms,
  // 4.4 s BEFORE the status bit -- healthy idle on this unit reads 0x09.
  Serial.printf("[frame] B>P %s   P>B %s\n",
                cn2::lastFrameHex(cn2::FROM_BOARD).c_str(),
                cn2::lastFrameHex(cn2::FROM_PANEL).c_str());
}

static void consoleHelp() {
  Serial.println(F("[con  ] s=status m=monitor c=CPU-relay w=wire "
                   "e/E=E5 mask on/off r=reboot W/X=radio on/off ?=help"));
}
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

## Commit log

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2026-08-21 fw: cap the untargeted cool-down flush
    byte3 = 0xFF with the intake bit set is the cool-down rinse: drain and intake
    together, no volume target, and no timeout at either end of the link. What
    ends it is the water stopping. Measured across the archive:
    washcycle 69.8 s sump 94 -> 30 -> 34 C 131 counts
    selfclean 64.1 s sump 56 -> 41 -> 43 C 121 counts
    selfclean2 114.6 s sump 55 -> 30 -> 37 C 164 counts
    Same Self-Clean program, 64.1 s once and 114.6 s another time, so it is
    neither a fixed duration nor a fixed volume. All three end just after the sump
    temperature bottoms out and starts back up, and a fixed setpoint is ruled out
    by the data itself (one run floors at 42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
    [cn2.cpp, config.h, test_main.cpp]
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2026-08-22 fw 1.2.0: guard the boot path, and stop WiFi taking the panel link down
    This board is screwed inside the appliance. No serial port, no BOOT button,
    no way to unplug the module -- "reachable over WiFi" is the only recovery path
    that exists, and 1.1.0 quietly put the payload in front of it.
    armWatchdog() ran at the END of setup(). That was fine while the payload
    started last: WiFi and OTA were already up, so a hang still left a way in.
    Bringing the CN2 link up first inverted it -- everything from cn2::begin() to
    net::begin() now runs before the radio, and a hang anywhere in there would sit
    forever with no watchdog to reset it and no OTA to recover through. Armed
    first now, and fed inside both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
    [cn2.cpp, config.h, main.cpp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]
2026-08-22 fw 1.3.0: frame-atomic forwarding — a CPU stall can no longer split a frame
    The E5 on a newer D8's touch panel, appearing a few seconds after every
    power-on with a byte-perfect link, comes down to tolerance asymmetry. Starved
    deliberately (/api/thin), the controller raises its comms bit after ~8 s
    without a panel frame. The panel is far stricter -- and WiFi association
    stalls the forwarding task for a measured ~96 ms (a flash write disables the
    instruction cache; no task priority helps), splitting whichever frame was
    mid-transmission. The controller never noticed; the panel latched E5.
    The stall moved when the radio moved: with the radio held off for 90 s, the
    same ~96 ms gap fired at t=9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
    [cn2.cpp, config.h, main.cpp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]
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2026-08-22 fw 1.4.0: refuse to relay a comms fault we can disprove (false-E5 filter)
    On this board status bit 6 -- what the panel renders as E5, "communication
    failure" -- is not only a comms fault. Measured, not inferred:
    * raised 2 s after EVERY power-on while the sump is still warm. Before WiFi
    associates, with the controller's own first frame clean, boot dead window
    0.00 s and zero bad checksums.
    * raised again the instant a dry stage ends -- the same 200 ms window the
    panel goes idle, frame counts matched exactly across it (d90/d90). An 8 s
    comms watchdog does not fire in 200 ms.
    * then held all night while the controller ran its 72 h storage on its own,
    heating the sump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
    [cn2.cpp, config.h, test_main.cpp]
2026-08-22 fw 1.4.1: recompute the checksum on ANY edit, and check what we emit
    1.4.0's false-E5 filter caused the fault it was written to suppress. It
    cleared bit 6 from byte 3 but the checksum was only recomputed when one of an
    ENUMERATED set of overrides was active -- lid, status mask, flow spoof, temp
    override -- and the new filter was not in that list. Every masked frame went
    out carrying the original checksum over an edited byte:
    A2 32 00 00 04 09 03 DE byte3 masked to 0x00, XOR still DE (=0x40)
    correct value is 9E
    The panel failed all of them, heard nothing, and reported a communication
    failure. Our own counters showed a perfect link throughout, because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
    [cn2.cpp, config.h]
2026-08-22 test: make the stale-checksum bug impossible to reintroduce
    The 1.4.1 fix was correct but untestable: the checksum decision lived inline
    in pump(), so no host test could reach it. That is exactly how the bug shipped
    -- and the repo's own rule says the pure logic belongs in cn2core precisely so
    the tests cannot drift into a parallel copy.
    So move the decision itself. cn2core::FrameTx now owns it and BOTH relay
    directions call into it; cn2.cpp no longer has an opinion about checksums.
    Eight tests, written to assert on the EMITTED FRAME rather than on which
    feature did the editing, so a rewrite added tomorrow is covered without anyone
    remembering to declare it:
    - the fixtures are themselve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
    [cn2.cpp, config.h, test_main.cpp]
2026-08-22 fw: measure the OTA link gap, keep the UARTs fed through it, and refuse to flash a machine that is busy
    Every OTA left the panel latching E5, and the cost of an update was pure
    guesswork: millis() cannot see across a restart, so nobody had ever measured
    how long the panel actually goes unfed.
    Measure it. The RTC clock survives esp_restart(), so the last forward is
    stamped from it into RTC_NOINIT before the image is written and the
    difference is read back on the next boot: ota_gap_ms in status, and a boot
    line that says outright when the gap was long enough to expect a latched E5.
    Shorten it. quiesce() never stopped relayTask -- the UARTs stay open and
    forwarding continues -- but Update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
    [cn2.cpp, ota_smoke_test.py]
2026-08-22 fw 1.4.3: fail CLOSED — one doubtful frame must not latch E5 forever
    Caught on the machine mid-cycle. Of 1152 frames the filter masked, exactly one
    went out unmasked:
    57.0s ago n=108 A2 27 00 00 04 0A 03 88 byte3=00 masked
    35.4s ago n=1 A2 27 00 40 04 0A 03 C8 byte3=40 LEAKED
    35.2s ago n=176 A2 27 00 00 04 0A 03 88 byte3=00 masked
    Checksums all valid, rx bad 0/0, tx bad 0/0. One frame is enough: the panel
    latches, so a momentary failure of the health check costs a power cycle.
    Fail-open was the wrong default against a LATCHING signal, and the argument
    for it does not survive scrutiny either. If the ESP->panel link were genuinely
    broken the panel would not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
    [cn2.cpp, config.h, test_main.cpp]
2026-08-22 fw 1.5.0: count bytes, do not time them — the actual root cause of the E5
    Every previous E5 fix treated a symptom. This is the cause.
    The rewrite path derived its position within a frame from the WALL-CLOCK GAP
    between bytes: a gap over a few ms meant "new frame, index 0". That holds only
    while the CPU keeps up with the wire, and it does not. WiFi association stalls
    the forwarding task ~96 ms (a flash write disables the instruction cache; no
    task priority helps). The bytes are not lost -- they queue in the UART FIFO --
    but they are DRAINED LATE, so the gap between the last byte before the stall
    and the first after looks enormous. The index reset fired MID-FRAME, the real
    byte 3 was counte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
    [cn2.cpp, config.h, test_main.cpp]
2026-08-22 ui 1.5.1: report the status byte the PANEL is told, not the one before filtering
    The engineering page headlined "E5" while the appliance itself showed no error
    at all, because the MACHINE card derived its state from st_real -- the
    controller's raw byte 3 -- and this controller flies bit 6 permanently while
    warm. The filter strips it, the panel is correctly told 0x00 and correctly
    displays nothing, and only our page still claimed a fault.
    Reporting an error the machine is not showing is worse than reporting none:
    it is the thing that sends someone looking for a fault that does not exist.
    - /api/app now decodes err/e5 from statusFwd(). The app must agree with the
    appliance in front of the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
    [config.h]
2026-08-22 fw 1.6.0: stop a panel-run fill that is getting no water
    Firmware cannot fix a flow meter that is not counting -- the pulses stop at
    the controller, upstream of us. What it can fix is the machine's response,
    which was to do nothing at all.
    Measured on this machine after the meter went silent: the panel held the
    intake bit for 1029 s -- seventeen minutes -- waiting for a count that never
    arrived, and neither end raised anything. Byte 2 stayed 0x00 for the entire
    capture. The ESP32 cycle runner has had a fill-stall guard since the start; a
    cycle the PANEL runs had none, which is the more dangerous case because it is
    the one people actually use.
    The hazard is not an empty tank. It is a DEAD M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
    [cn2.cpp, config.h, test_main.cpp]
2026-08-22 fw 1.7.0: suppress bit 6 at the owner's request, and replace what that removes
    The controller on this machine raises status bit 6 with no cause visible
    anywhere on the wire, and the PANEL is what acts on it: measured at 5 Hz with
    no filtering, the controller set the bit and the panel dropped every load
    0.2 s later. Masking it therefore stops the panel aborting.
    It also removes whatever protection that bit represents, and nobody knows
    what that is. So this does not just delete a guard -- it replaces it.
    cn2core::HeatCeiling strips the heater bits (water heat 0x04, air heat 0x08)
    from the forwarded panel frame above a ceiling and holds them off until the
    sump drops clear of it. Heat with no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
    [cn2.cpp, config.h, test_main.cpp]
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2026-08-22 tools: end-to-end self-diagnostic
    Checks what the link can actually prove, and says plainly what it cannot --
    a load with no sensor on it can be commanded but not confirmed, and reporting
    "pass" for those would be a lie. They come back as "not measurable".
    Covers: board health and boot-loop state, link quality in BOTH directions
    (including tx_bad, which nothing was watching until a stale-checksum bug shipped),
    byte-exact forwarding, RX overflow, relay stall, frame XOR validity on every
    emitted frame, pin map, both transmit stubs via the shifter's own pull-up,
    controller fault bits, lid sensor agreement, the rewrite path (edit a byte,
    confirm the checksum is recomputed), each load bit reachi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
    [selftest.py]
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2026-08-23 fw 1.9.0: cut mains from the ESP32 when the controller strands a load
    Root cause, from six occurrences across four captures: this controller raises
    status bit 6 when a heater is commanded and the temperature does not respond.
    It stalls dead at 44 C during wash+heat (41,42,43,44,44 -> bit 6, twice,
    identically) and goes flat or falling during dry. That is heater-malfunction
    detection, not the "communication failure" the BW05 manual's E5 implies -- the
    label came from the OTHER machine and cost a day.
    Once bit 6 is set the controller stops acting on load commands, INCLUDING the
    panel's end-of-cycle release. The panel says finished and drops every bit; the
    locked controller never processes it,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
    [cn2.cpp, config.h, kasa.cpp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]
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2026-08-23 docs/tools: controlled heat tests, and the two rules that actually matter
    Mirror of the private repo's update. Four heat stages driven from the ESP32
    with the panel idle: wash+heat at 20 and 80 counts, steam, and dry. All ran
    clean.
    Heat rate does NOT determine the lockout -- 80 counts at 0.0801 C/s finished
    clean while an earlier run locked out at 0.077 C/s, and this one went straight
    through the 44 C where two earlier runs stalled.
    The dry result is the useful one: with the air heater and blower running the
    sump reads a steady DECLINE. That is physics, not a fault -- the blower cools
    the sump, the air heater warms air, and this machine has only the sump NTC.
    A "heater commanded -> temper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
    [stuck_watch.py, volume_test.py]
2026-08-23 fw: default the flush cap OFF — its core assumption does not hold here
    Removed at the owner's request after it made a real cycle worse, and the
    default follows because the reasoning behind it was wrong, not just the timing.
    The cap strips the intake bit once an untargeted 0xFF flush has run too long,
    on the assumption that the controller would then end the stage the way it
    always had: water stops arriving, the sump empties, the temperature turns
    around, the stage completes. That is what the captures from the original unit
    showed.
    It does not hold on a controller that has locked out. A locked controller ends
    nothing. Observed this morning: the panel sat in a single flush for 2131 s --
    35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
    [config.h]
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2026-08-23 app 1.10.0: touch-sized load controls, and fix a race in the matrix test
    The engineering page renders each load bit as a 30 px chip -- fine with a
    mouse, unusable with a thumb. The user app now carries a LOADS card: six 64 px
    buttons, three across, tap to drive a bit directly, plus RELEASE ALL.
    Colour carries the distinction that matters: BLUE means the machine itself is
    driving that load, GREEN means you are. The subtitle says outright when the
    controller is locked, because in that state the buttons do nothing and the
    reason is not visible from the front of the machine.
    Two states per bit, not the engineering page's three. On a phone the useful
    action is 'make this run', and three states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
    [config.h, lockout_matrix.py, unlock.py]
2026-08-23 tools: lockcheck.py — prove whether the controller accepts commands
    Status bit 6 is an INDICATOR, not a proof. It has tracked "loads ignored" in
    every observation, but it is still an inference from a bit whose meaning nobody
    has documented -- and inferring from an undocumented bit is how most of this
    week's wrong turns started.
    lockcheck.py is the proof: command the intake motor and watch the flow meter,
    the only load on this machine with a sensor on it. Intake only, no heater bit
    ever commanded, override released in a finally, and it refuses outright if the
    panel is mid-cycle. Exit 0 = accepting commands, 1 = not.
    First run, against a locked machine: bit 6 said LOCKED, the probe agreed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
    [lockcheck.py, unlock.py]
2026-08-23 tools: unlock2.py — escalating unlock, verified by probe, attempts logged
    Mirror of the private repo. Encodes no rule, because every rule asserted so far
    has been falsified. Escalates 60 -> 120 -> 180 -> 300 -> 600 s, verifies each
    attempt with the definitive flow probe rather than status bit 6, and logs every
    attempt so the rule can be derived from data.
    First run: 60 s and 120 s at 30 C both failed, 180 s at the same temperature
    cleared it and the probe confirmed. One trial cannot separate cause from
    coincidence; the log exists so repeated runs can.
    Restores the relay in a finally so being killed mid-cut cannot strand the
    appliance, refuses to cut while loads are commanded, and waits f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
    [unlock2.py]
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2026-08-23 self-healing cycles: NVS resume, lock webhook, breaker (1.13.1)
    The lockout recovery is a mains cut, and the plug also powers the ESP32 --
    so surviving recovery had to be built, not assumed:
    - Cycle progress persists to NVS at every stage boundary and is cleared
    on any normal exit. Writes are DEFERRED to the main loop: the first
    build wrote from relayTask and a flash write stalls the single C3 core
    past the task watchdog, panicking the board at the first live stage
    boundary.
    - POST /api/cycle_recover resumes the persisted cycle, restarting the
    interrupted stage from zero (fills re-measure; the water flag carries
    over because the water is physically still there).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
    [cn2.cpp, config.h, d8_watchdog.py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]
2026-08-23 WIRE mode: forward in the GPIO matrix, not in software (1.14.0)
    The decisive test finally ran: with the module unplugged entirely, the
    touch-panel machine runs clean. The lockouts were OURS. Byte-perfect
    forwarding had exonerated the data and nothing else -- the two remaining
    suspects are store-and-forward delivery timing (a stalled task bunches
    panel frames; this controller LATCHES its starvation bit where the old
    one only flashed E5 -- the FIFO-batching comment in openPorts was the
    same lesson, milder) and ESP32 WiFi draw on the CN2 pin-4 rail. The lock
    rate accelerating in lockstep with added HTTP monitoring traffic points
    the same way.
    WIRE mode closes the timing suspect completely: the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
    [cn2.cpp, config.h, net.cpp]
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2026-08-25 relay-path profiler, early boot bridge, TX cap removed (1.15.0)
    /api/prof answers 'what stalls the forwarding task': a gap histogram from
    the relay loop (victim's view) plus per-suspect timers at the call sites --
    every HTTP request served, every deferred NVS flush, every webhook POST
    (suspects' view). First controlled matrix, machine idle: steady-state CPU
    relay never gapped past 9.6 ms even under 4-client HTTP hammering, NVS
    writes, and full /dev page serves -- one HTTP call blocked its own task for
    1.77 s and the relay did not care (priority preemption works). The historic
    96 ms stall is a BOOT-TIME WiFi-association artifact, not steady state.
    earlyBridge() wires the CN2 pads through the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
    [cn2.cpp, config.h, main.cpp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]
2026-08-25 wireSet(false): force the TX reattach setPins() silently skips (1.15.1)
    HardwareSerial::setPins() consults the core's peripheral bookkeeping and
    no-ops when the pin numbers are unchanged -- and the wire bridge's theft of
    the pads through the GPIO matrix is invisible to that bookkeeping. So every
    switch back to CPU relay mode since wire mode shipped left the bridge
    connected and the UART TX signals detached: pass-through kept working
    (through the bridge), while every synthesized byte -- load overrides, lid
    forcing, the cycle runner, intake fills byte-identical to the panel's own --
    went into a dead UART. Twelve hours of ghost hunting (mode bytes, drain
    choreography, atomic transitions, lid sw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
    [cn2.cpp, config.h]
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2026-08-25 self-contained consolidation: postmortem, junk removal, prefs fix (1.16.3)
    docs/postmortem.md is the evidence-based close-out of the E5 investigation:
    bit 6 = the controller's panel-frame-starvation latch (five lines of
    evidence), the Aug 23 storm's mechanism proven but per-event trigger
    honestly unclaimed, the wire-vs-CPU comparison retracted (setPins no-op put
    bridge forwarding in both arms), the non-bit-6 errors (E1, autonomous
    flush, link decay) separated out, and the measured impossibility of
    self-power-cycle on an HS103 (three mechanisms tested).
    Firmware: hook.cpp/webhook removed (no external daemon exists to call),
    FlushCap and DrainExtend removed (dead features; 20 host tests retir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
    [cn2.cpp, config.h, main.cpp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]
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2026-08-27 tests: E5 model — reproduce every firmware-caused E5, forbid recurrence
    An E5Model encodes what three days of evidence established: the controller
    latches when checksum-valid panel frames stop arriving, and stays latched.
    Three reproduction tests replay the historical bug classes against it (the
    1.4.0 stale checksum, desync-alias garbage, plain forwarding silence) and
    assert they LATCH -- the requested 'unit test that reproduces E5'. Two
    prevention tests then prove the current emit pipeline cannot produce any of
    those streams: continuous valid frames through FramePos+FrameTx including a
    live mid-stream rewrite, and alias recovery that goes to pass-through
    before the latch threshold. Any fu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
    [cn2.cpp, config.h, test_main.cpp]
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2026-08-27 plug driver: Shelly Gen2+ support alongside Kasa (1.17.0)
    The D8's outlet moves from the Kasa HS103 to a Shelly Plug US Gen4. The
    protective-cut driver gains a plug type (NVS 'plugt'): Shelly is one HTTP
    GET (/rpc/Switch.Set) -- no framing, no cipher -- and the device is
    configured initial_state=on, so mains restoration re-energises by itself:
    the HS103's stranding failure mode (relay restores to last state, all
    timer mechanisms broken) is retired with it. /api/kasa gains type=, keeps
    full Kasa compatibility. Dry-run verified end to end on the empty Shelly:
    reachability, firmware-driven cut, restore. tools/shelly.py is the host
    helper (status/on/off/cycle).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
    [config.h, d8_logger.py, kasa.cpp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]
2026-08-27 self power cycle + on-chip lockout self-heal (1.17.1)
    The Shelly's toggle_after gives this board the one thing the HS103 could
    never: a mains cycle it survives. kasa::powerCycle(hold_s) sends a single
    GET -- the plug opens its relay, this board dies, the plug's own timer
    restores power. Proven end to end through /api/kasa?cycle_s=8 (board died
    and returned, uptime reset). Refused on Kasa plugs, where it would strand.
    selfHealTick() finally puts the lockout watchdog ON the chip: bit 6 held
    60 s with the panel idle triggers escalating self power cycles (120/180/
    300 s holds), three strikes then stop -- a latch that survives 180 s cuts
    is hardware, not something to churn a relay over -- with t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
    [cn2.cpp, config.h, kasa.cpp]
2026-08-27 app: CUT MAINS becomes POWER CYCLE on a Shelly plug (1.17.2)
    The button adapts to the plug's real capability (plug_cycle in /api/app):
    on the Shelly it runs the true self-restoring cycle (off 8 s, auto-return,
    board reboots and resumes); on a Kasa it stays the honest one-way CUT with
    the restore-it-yourself note, because that plug cannot bring power back.
    Two-tap arming unchanged.
    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
    [config.h]
2026-08-27 self-heal is opt-in with a human-only breaker (1.17.6) — the pump-night lesson
    The Aug 26-27 night: the self-heal's breaker self-reset after ten clear
    minutes, but a MARGINAL controller input reads clear in stretches while
    staying broken -- so the loop power-cycled the machine all night, and every
    controller boot runs its own drain+intake flush. The Shelly's meter priced
    the lesson: ~292 Wh of water churn. Now: the feature is OFF by default
    (NVS 'heal'), and the strike counter resets only via POST /api/heal --
    never by time, never by a flickering input. Also in this build: 1.17.3's
    wsr pin gating (GPIO10 untouched when the relay feature is off), 1.17.4's
    instantBridge (pads bridged in setu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
    [cn2.cpp, config.h, main.cpp]
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2026-08-28 config: pin-map defaults aligned to the as-built wiring (1.17.8)
    An external review flagged that instantBridge's hardcoded map (5/6/3/4)
    contradicts config.h's defaults (3/4/5/6). The mismatch was real; the
    review's proposed direction was inverted. Field evidence settles physical
    truth twice over: frames decode ONLY under 5/6/3/4 (zero frames under the
    old defaults after the NVS wipe), and an intake command emitted on txb=6
    moved real water -- impossible if GPIO6 were the panel's output. So the
    defaults now match the copper (this module was rewired 2026-08-25 and
    differs from docs/build.md), which also defuses the landmine the wipe
    exposed: defaults that disagree with the wiring silently kil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
    [config.h, main.cpp]
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2026-08-29 firmware 1.18.1: USB serial console + radio-off mode (E5: WiFi exonerated)
    The radio was the last unexonerated load in the E5 investigation, and it
    could not be switched off because every telemetry path rode on it. This
    adds a USB serial console (s/m/r/W/X) and an NVS "nowifi" mode that skips
    net/web/kasa entirely, so the module can be run and observed with the
    radio completely dark.
    Result, first run: the controller still latches. Captured over serial with
    the radio off, the machine boots clean (A2 16 00 82 04 00 03 31, no latch)
    and sets bit 6 exactly 5 s later with ZERO bad frames in between. WiFi
    power draw and RF are therefore NOT the trigger -- the theory that survived
    three days is d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
    [config.h, main.cpp]
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

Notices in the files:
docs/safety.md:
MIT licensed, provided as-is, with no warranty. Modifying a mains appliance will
